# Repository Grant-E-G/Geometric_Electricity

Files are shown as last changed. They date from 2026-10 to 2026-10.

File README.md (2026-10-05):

# Geometric Electricity

A passive LC circuit experiment comparing 85-node Euclidean and hyperbolic disks.

The [project outline](notes/one_and_done_hyperbolic_euclidean_board.md) describes the intended board. The [design and measurement plan](notes/research_plan.md) records calculations, equipment, decisions and remaining validation. Open [the KiCad project](hardware/geometric_electricity.kicad_pro) for the current CAD draft; [reproduction commands](code/README.md) generate simulations and verify connectivity.

The hardware is a design draft. Generated manufacturing files remain previews until routing, procurement and assembly checks pass. Bench validation follows assembly.

## Repository Layout

- `notes/`: research plans, reading notes, project logs, and informal planning.
- `math/`: definitions, theorem targets, proof sketches, examples, and open questions.
- `latex/`: manuscript source, macros, bibliography, and TeX inputs.
- `latex/render/`: rendered PDFs and TeX build products. This directory is ignored by git.
- `code/`: one consolidated simulation, CAD-generation and measurement-analysis script.
- `hardware/`: one KiCad project, sparse adjacency/metric data, BOM.
- `build/`: ignored simulation reports, figures, native checks and manufacturing previews.
- `sources/`: source material used during research.
- `sources/pdfs/`: local PDF references. PDF files are ignored by git.

## Working Sequence

1. Read the design/measurement plan and the original outline.
2. Reproduce simulations, probe loading, tolerance and defect sweeps.
3. Generate the KiCad schematic and placement; route and run native checks.
4. Confirm a landed total **below $200**, including PCB/stencil, shipping, tax,
   consumables and spares. Component precision must not break this constraint.
5. Verify the stencil/assembly map, assemble with a measured reflow profile and
   calibrate the RF fixture and probes.
6. Measure low-order responses and pulses, fit overlapping modes where justified,
   and state partial-spectrum limits explicitly.

All generated reports/previews stay in ignored `build/`. With the user-provided
PCBWay shipping-inclusive quote and $10 stencil, the proposed TDK parts give
$170.34 for lead-free HASL or $194.81 for ENIG. These totals retain $15 component
shipping, $20 tax/import and $20 contingency allowances. Component delivery and
any additional stencil shipping remain unconfirmed. The current Abracon BOM
costs $181.48 with HASL; its ENIG scenario exceeds $200. No purchasing or physical
measurements have occurred.

## Coding Guidelines

- Prefer Rust for implementation work. Use Python as a backup, with type checking.
- Prefer functional code when possible. Relax this guideline when it causes performance issues.
- Long functions are fine.
- Avoid inheritance. Object-oriented design is generally discouraged.
- Avoid excessive code fragmentation. Longer files are acceptable when they keep related logic together.
- Lint code aggressively. Use Black for Python formatting.
- Shorter code is almost always better code.

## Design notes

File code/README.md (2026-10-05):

# Reproducible LC design

`design.py` keeps graph generation, electrical models, KiCad generation and
measurement post-processing together. Python is the backup language allowed by
the repository guidelines: SciPy and KiCad's native `pcbnew` interface make it
appropriate here. No extra simulator framework or application is introduced.

Use KiCad 9, ngspice, system Python 3.10+ with `pcbnew`, and a virtual environment
that can see system packages:

```bash
uv venv --python /usr/bin/python3 --system-site-packages .venv
uv pip install --python .venv/bin/python numpy==2.2.6 scipy==1.15.3 matplotlib==3.10.9 black==26.10.0 mypy==2.4.0 ruff==0.16.10
.venv/bin/python code/design.py build --trials 200
.venv/bin/python code/design.py check
.venv/bin/black --check code/design.py
.venv/bin/ruff check code/design.py
.venv/bin/mypy --ignore-missing-imports code/design.py
```

`build` regenerates the schematic, **placed PCB**,
graphs and BOM. It replaces existing PCB edits/routing; preserve manual changes
before using it. `check` verifies the current board and schematic against the
independently reconstructed graphs without overwriting the copper.
`simulate` reruns the mathematics, tolerances, AC response and two transient
models without regenerating the KiCad files. All intermediate files, plots,
ngspice decks and manufacturing previews are in ignored `build/`.

Run the complete computational measurement suite, including the original
simulations and fresh independent ngspice references:

```bash
.venv/bin/python code/design.py test-simulations --trials 200
```

This preserves the routed PCB and schematic. It adds source-rank/visibility,
inductor SRF and loss, capacitor ESR/ESL and trace/return inductance, signed mutual
coupling, uneven stray capacitance, noisy current reconstruction and scan-probe
deembedding, extended disorder/localization, common-pole/spatial-residue recovery,
held-out frequencies, assembly faults, moving-probe pulses and finite-spectrum
truncation tests. Noise, calibration errors and parasitic values are explicit
sensitivity assumptions; they are not measurements or field-extracted PCB data.
Failed recovery scenarios remain in the report rather than being counted as
numerical failures or hidden. A small fit residual alone does not establish
correct poles or spatial modes.

Generated outputs include:

- `simulation.json` and `simulation.png`: seed, Monte Carlo scenarios, frequency
  clusters, probe/stray sweeps, C choices and illustrative responses.
- `E/H_simulation.npz`: q, voltage eigenvectors, frequencies and loaded AC maps.
- `E/H_pulse.npz`: ideal Gaussian current pulse with series inductor loss.
- `E/H_loaded_pulse.npz`: Gaussian voltage pulse, 50 Ω generator, 1 kΩ injection,
  and two 10 pF probes, simulated independently in ngspice.
- `spice_validation.json`: independent matrix/modal-versus-ngspice errors.
- `test_simulations.json` / `test_simulations.png`: computational measurement
  coverage, parameters, failures and engineering limits for both geometries.
- `E/H_nonideal_ac.npz` and `E/H_nonideal_spice.cir`: nonideal sweeps and separately
  stamped ngspice models, including mutual coupling.
- `E/H_pulse_tests.npz`: complete repeated 85-node scans with a moving probe,
  alongside one acquisition with the scan probe held fixed.
- `E/H_recovery_input.npz` / `E/H_recovery_fit.npz`: the last recovery case;
  all noise levels and seed comparisons are retained in `test_simulations.json`.
- `verification.json`, `erc.json`, `drc.json`: graph/pin and native rule checks.
- `budget.json`: component quantities, spending allocations and unconfirmed quote gates.
- `probe_map.pdf` / `probe_map.csv`: actual signal-pad coordinates, KiCad reference
  and nearest ground contact. Ground contacts include return vias and ground test pads.
- `manufacturing-preview/`: Gerbers including F.Paste, Excellon drills and an
  explicit NOT_FOR_FABRICATION marker; `positions.csv` and `schematic.pdf` / `assembly.pdf` (DNP footprints crossed out).

Record the actual assembly state, L/C/Q calibration, source, scanned node,
probe count, frequency and channel calibration with acquired data. The documented
measurement procedure is in `notes/research_plan.md`.

For one stopped scope acquisition, the optional LAN capture command sets the
waveform readout to RAW ASCII and reads CH1/CH2/CH3 from the same frozen record:

```bash
.venv/bin/python code/design.py capture --host SCOPE_IP --csv build/capture.csv
```

It assumes a SCPI socket at TCP 5555. The command has **not been tested against
the user's scope**; validate this interface and scaling with a known sine first,
or export CSV manually. The front panel must already have 10× probe scaling,
channels enabled and suitable acquisition settings. It does not configure or
control the JDS6600. The first 10,000 RAW samples are read; ensure that interval
contains the desired signal. SCPI failures are reported rather than hidden.

For manual or scripted captures, use exactly these columns (volts already scaled
to the probe tip): `time_s,vin_v,vsource_v,vscan_v`. Analyze a settled sine window:

```bash
.venv/bin/python code/design.py phasor --csv build/capture.csv --frequency 6000000 --sense 1000 --probe-pf 10
```

This fits sine/cosine/DC terms and subtracts source-probe current. If fixture
calibration supports a lumped extra source capacitance, pass `--fixture-pf VALUE`
to subtract it as well (default zero; do not guess it). Distributed fixture
impedance requires a fuller calibration. It assumes a
real sense resistance and calibrated relative channel phase/gain. It leaves the
moving scan probe's network loading in the transfer response; see the explicit
deembedding procedure in the design plan. A synthetic capture checks current
orientation and source-probe subtraction analytically during build/check.

For calibrated, current-normalized complex frequency responses, supply an NPZ
with `frequency_hz[n]` and `impedance_ohm[n,channels]`. Correct moving-probe loading
first; a moving load does not have exact common poles. Seed distinct resonance
clusters from a coarse sweep (one pole pair per degenerate cluster):

```bash
.venv/bin/python code/design.py fit --responses build/responses.npz --initial-mhz 4.42 4.63 --background-order 2 --output build/poles.npz
```

Variable projection fits conjugate pole pairs with complex residues and a local
complex polynomial background on the positive-frequency window. The polynomial
approximates other modes locally; it is not a global passive network model.
Orders 0–4 are supported; compare orders and adjacent-mode counts to detect
model bias. Output includes damping, undamped frequencies,
residues, residual RMS and Jacobian condition. A synthetic two-channel overlap
case checks pole/damping recovery independently; the extended suite also tests
responses of the entire 85-node network with four sources and all scan nodes.
Output NPZ stores complex `background_coefficients[order+1,channels]`,
`background_center_mhz` and `background_scale_mhz`; evaluate the polynomial at
`(frequency_mhz-center)/scale`. Test several seed sets and withhold frequencies
to assess model error. Convergence is not completeness or
identifiability; residues still need calibrated spatial factorization before
becoming the real orthonormal vectors required below.

For **fitted** real orthonormal eigenvectors, provide an NPZ containing `q[m]`
and `vectors[85,m]`. Uniform-L voltage vectors can be used directly; for disordered
L, convert to coordinates of the self-adjoint operator described in the plan.
Raw voltage maps at unresolved peaks are not eigenvectors.

```bash
.venv/bin/python code/design.py derive --eigenpairs build/E_simulation.npz --output build/E_analysis.npz
```

This produces the finite-graph heat kernel/trace, zeta at s=1,2,3, Q inverse and
participation ratios. Fewer than 85 modes are explicitly marked partial. Only
when recovery of **all lowest m modes** has been established may
`--lowest-modes-complete` be used to add rigorous heat-trace/zeta tail bounds.
This command is not a common-pole fitting implementation.

For uniform-time pulse scans, provide `time_s[time]`, `voltage_v[time,85]` and
`source` in an NPZ:

```bash
.venv/bin/python code/design.py propagate --waveforms build/H_loaded_pulse.npz --geometry H --output build/H_propagation.npz
```

This extracts Hilbert envelopes, masked instantaneous phases and distances in the
true metric and embedding. Compare only reproducibly triggered scans before
reflections dominate. Hilbert phase alone does not establish causal arrival time.

The reproducible assertions and native checks are meaningful electrical/topology
checks, not substitutes for physical calibration, noise characterization or
fabrication readiness. Read the current design status before using any Gerbers.

Export/import routing through a Specctra-compatible router without regenerating
the schematic or placement:

```bash
.venv/bin/python code/design.py route-export
# Route build/routing.dsn in a compatible router, saving build/routing.ses.
# Preserve the ground returns; in Freerouting use -inc GND and -mt 0.
.venv/bin/python code/design.py route-import --session build/routing.ses
.venv/bin/python code/design.py check
```

The exported design assigns ground to its own class and protects its existing
return copper and excludes pours from the router's copy. The initial signal pass
may skip that class; a final repair pass must also connect remaining ground items.
Native refill/connectivity checks remain mandatory.
The saved board was routed with Freerouting 1.9.0, then repaired locally in KiCad
copper geometry. The initial router command was `java -jar freerouting-1.9.0.jar
-da -de build/routing.dsn -do build/routing.ses -mp 20 -mt 0 -inc GND`; the ground
repair pass omitted `-inc GND`. This version required a local graphical display.
Preserve the saved routed PCB: `build` produces placement, and a new router
run can produce different copper. `check` is the authority for the current native
connectivity result. Refresh exports after copper edits using
`python -c 'import sys; sys.path.insert(0, "code"); import design; design.export_preview()'`
with the same virtual environment, then run `check` again. Export refresh also
updates the ground-contact map and opens selected standard ground vias on the
front solder mask.
Import refills the ground plane. A successful router import is not a passing
DRC or permission to fabricate. Current manufacturing output is explicitly a
preview. The budget uses user-provided PCBWay fabrication/shipping and stencil
quotes; component shipping, consumables, tax/import and contingency remain allowances.

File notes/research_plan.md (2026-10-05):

# Geometric Electricity: design and measurement plan

Design baseline: 2026-10-05. The original idea remains in
[the project outline](one_and_done_hyperbolic_euclidean_board.md).

## Question and scope

Can one passive PCB distinguish the low-order spatial spectra and propagation
of Euclidean and hyperbolic disks using the equipment already available, and
support reproducible finite-graph spectral analysis?

Keep one board, one assembly, two independent 85-node networks, common ground,
and no active switch matrix. The intended comparison is between induced regular
triangular disks with coordination six and seven. Electrical traces do not set
the simulated metric; connectivity does. Physical placement coordinates and
mathematical embedding coordinates must remain separate.

## Equipment and measurement contract

The user confirmed a Rigol DHO924S (four channels, 250 MHz), JDS6600-60M generator,
PVP3150 probes, DE-5000 with TL-21/TL-22 fixtures, and T-962 oven. There is no VNA.
Use 10× probes, modeled as 10 MΩ in parallel with 10 pF at **each** connected
network node. Also simulate 15 pF uncertainty and 50 pF loading. CH1 measures
actual voltage before the injection resistor; CH2 remains at the source node;
CH3 scans the response. CH1 capacitance is on the generator side of the resistor,
not another network-node load. Ground every probe to the common ground.

The JDS6600's sine-frequency limit does not establish pulse rise time or arbitrary
waveform bandwidth. Confirm its delivered pulse on CH1 and use the measured
waveform for propagation interpretation. The DE-5000 is useful for loose-part
screening, but its 100 kHz ceiling cannot certify MHz Q. Do not treat measured
100 kHz Q or DC resistance as the loss at a circuit resonance.

## Operator and exact boundary convention

Let A be the adjacency matrix and d the retained degree. For each missing neighbor,
install one extra coupling capacitor to ground. Then

\[
Q=\operatorname{diag}(d)-A+\operatorname{diag}(q-d)=qI-A.
\]

This is a positive Dirichlet operator, not the zero-mode-bearing free-boundary
Laplacian. The default hardware has 330 pF per retained edge and **330 pF per
missing neighbor**, including multiple capacitors in parallel where necessary.
No special 990 pF or 1320 pF purchase is required. Removing all capacitive
boundary terminations would produce the free graph Laplacian; removing only a
few makes a local boundary defect and must not be called a global Neumann change.

For uniform L and C,

\[
J(\omega)=i\omega C Q+\frac{1}{i\omega L}I,
\qquad f_k=\frac{1}{2\pi\sqrt{LCq_k}}.
\]

Ascending q means **descending electrical frequency**. Low-order drum modes
are the highest resonances. With losses, the simulator stamps the full series
R-L branch rather than adding an arbitrary damping term to a graph Laplacian.
The Q sweeps use constant R = 2π(8 MHz)L/Q; consequently Q varies with frequency.
These are engineering sensitivity scenarios, not manufacturer broadband models.

With inductance disorder, the measured voltage eigenvectors are generalized
modes of C_matrix v = (1/ω²) diag(1/L_i) v. Ordinary orthonormal eigenvectors are
obtained after dividing voltage coordinates by sqrt(L_i). The self-adjoint
operator is S = diag(sqrt(L_i)) C_matrix diag(sqrt(L_i))/(L_nom C_nom).
Do not apply uniform-L orthogonality or heat-kernel formulas blindly to raw
voltage maps from a disordered circuit.

## Graph construction and mathematical validation

The Euclidean disk consists of axial triangular-lattice coordinates satisfying
 a²+ab+b² ≤ 21. It has 85 nodes, 222 retained edges and 66 missing-neighbor
capacitors. Graph-distance shells contain 1, 6, 12, 18, 24, 24 nodes.

The hyperbolic disk is the radius-three graph ball of the regular {3,7}
tessellation. Construct neighbors with Poincaré disk isometries and sevenfold
rotations. Its edge distance satisfies cosh(ell)=cos(2π/7)/(1-cos(2π/7)); the
embedding uses curvature -1. It has shells 1, 7, 21, 56, 196 retained edges and
203 missing-neighbor capacitors. Distances for the curvature -4 convention in
the reference are half these distances. This graph is generated independently;
we have not claimed equality to the reference's original node numbering or its
archived Euclidean adjacency file.

Checks cover node count, connectivity, degree, cyclic symmetry, positivity,
row sums, eigen-equation residuals, independently exported schematic pin nets,
and PCB capacitor incidence plus boundary multiplicities. Pin/net parity alone
does not prove that copper is routed: KiCad DRC must separately pass.

## Electrical scale and simulation findings

At 1 µH / 330 pF the nominal full spectrum is:

| Geometry | Minimum electrical frequency | Maximum electrical frequency |
| --- | ---: | ---: |
| Euclidean | 2.9455 MHz | 15.6483 MHz |
| Hyperbolic | 2.8070 MHz | 7.6601 MHz |

Thus the outline's estimated 1.4–9.6 MHz window is not the spectrum of these
specific disks. Both computed windows are accessible to the confirmed generator
and scope. Start with a 2–17 MHz sweep and refine to ≤5 kHz spacing near selected
peaks. The continuum interpretation is restricted to low-order modes.

The first six distinct nominal resonance clusters, in increasing q order, are:

| Geometry | Electrical frequencies, MHz |
| --- | --- |
| Euclidean | 15.6483, 9.9262, 7.5118, 7.0204, 6.1951, 6.1108 |
| Hyperbolic | 7.6601, 6.1478, 5.4316, 4.9893, 4.6011, 4.4550 |

These frequency lists by themselves do not label radial/angular modes. Determine
spatial profiles and angular content before identifying a reordered radial mode.

Seed 20261005, 200 trials per combination, independent uniform L tolerance,
independent edge C tolerance (including the budget ±5% case), conservative
lumped boundary-bank tolerance,
and 2 pF uniform stray capacitance:

| L tolerance | C tolerance | Scenario Q at 8 MHz | 5th percentile worst first-six-cluster subspace overlap, E / H |
| --- | --- | ---: | ---: |
| ±10% | ±5% | 36 (budget baseline) | 0.827 / 0.852 |
| ±10% | ±2% | 45 | 0.850 / 0.870 |
| ±5% | ±2% | 50 | 0.962 / 0.968 |
| ±2% | ±2% | 50 | 0.994 / 0.991 |

All scenarios use the same random draws within each geometry for a fair
comparison. Q affects the linewidth screen, not the lossless eigenspace overlap.
For the budget case, the 95th percentile maximum first-12 frequency shift is
about 1.6% for E and 1.7% for H. This is a simulation of bounded independent
uniform variation, not a manufacturing yield guarantee. Correlated lot errors
can move the common frequency scale and must be checked experimentally.

Degenerate eigenspaces are compared by principal angles after eigenvector-based
assignment; an arbitrary rotated basis inside a degenerate space is not counted
as a failure. Disorder and spectral resolution are separate issues. The cheap
10% option does not destroy all low-order identification, but gives worse spatial
fidelity. Higher-order modes are not covered by these low-order overlap numbers.
The gap-versus-linewidth screen is deliberately conservative: Q≈50 does not
separate all first-six clusters; the hyperbolic 4.601/4.455 MHz pair is especially
close. Q≈100 improves this screen substantially. It does not follow that 85
individual peak maps will be recoverable with either part.

With 2 pF stray at every node and two 10 pF probes at the designated intermediate
source and boundary node, the largest first-12 frequency shifts are about 1.08%
for E and 0.26% for H. Uniform stray is a simplification; copper extraction,
uneven node capacitance, inductor SRF, mutual inductance, capacitor ESR/ESL,
connector/cable capacitance and channel calibration still need assessment.
The simulations sweep C = 220, 330, 470, 680 and 1000 pF. Retain 330 pF as the
baseline because it preserves useful MHz bandwidth with modest modeled probe
loading. Changing C alone does not improve normalized mode spacing or Q.

Independent ngspice AC checks agree with the matrix solution to <10⁻⁶ relative
error. The ideal current-pulse transient agrees within 0.1% of peak voltage.
A second ngspice transient includes a 50 Ω generator, 1 kΩ injection resistance
and source/scan probe capacitance. Synthetic waveforms are predictions, not
measurements of the JDS6600's pulse or a fabricated board.

## Extended testing simulations

Run `.venv/bin/python code/design.py test-simulations --trials 200`. This
regenerates the original simulations and independent ngspice references before
running the additional tests; it preserves the routed CAD. Results and plots
are in `build/test_simulations.json` and `build/test_simulations.png`. Generated
artifacts stay ignored; the implementation stays in the existing design script.

The suite covers source visibility, moving-probe deembedding, assumed measurement
noise and calibration errors, component/lot tolerance and localization, coil
self-capacitance, capacitor ESR/ESL, trace/ground inductance, mutual inductance,
assembly faults, loaded pulses, full-network overlapping-pole recovery, and
partial heat/zeta/Green reconstruction. The nonideal circuit is independently
cross-checked against ngspice; matrix heat/Green calculations are checked against
independent matrix exponential/inverse calculations. Checks include passivity
and source/probe loading, with 10 pF per actively probed node.

Important numerical findings from the seeded 200-trial run:

- Four selected sources span the first six ideal mode clusters for both graphs.
  A center source alone misses symmetry modes. Rank does not establish practical
  signal-to-noise or identifiability of the complete spectrum.
- The fifth-percentile minimum overlap of the first six mode subspaces is about
  0.82/0.83 (E/H) for ±10% L, ±5% C; ±5% L improves this to 0.95/0.96.
  ±20% L with ±5% C drops it to 0.60/0.45. These are normalized self-adjoint
  subspaces, with independently sampled boundary capacitors; they differ from
  the earlier conservative, correlated-bank tolerance calculation above.
- Exact simulated moving-probe deembedding recovers the intrinsic maps to
  numerical precision. Assumed 0.5% gain error, 0.5 degree phase error and
  2 pF probe-capacitance uncertainty give roughly 2–3% map error through much
  of the resonant band. Noise trials assume independent white sample noise,
  20 cycles at 1 GS/s and 200 mVpp generator output. These assumptions are
  sensitivity cases, not measured Rigol noise specifications.
- Loaded-pulse state-space and ngspice results agree within 0.1% of peak.
  Repeating a scan with the probe moved changes the reconstructed wave map by
  about 1.3% relative to a fixed-probe reference. Threshold arrivals and
  voltage-weighted metric radii are diagnostics, not causal propagation speeds
  or proof of unreflected geodesic transport.
- Full-network fits use multiple sources, held-out frequencies and two seeds.
  Q=36 supports useful selected overlapping-mode recovery at low added noise;
  Q=20 produces substantially worse spatial recovery even with very small fit
  residuals. Convergence and a small residual alone do not qualify eigenpairs.
- With only 12 modes, the dimensionless t=1 heat trace captures about 90% for
  both graphs, but zeta(s=1) captures only 47%/31% (E/H). The corresponding
  Green inverse has about 34%/65% relative Frobenius error. Report partial
  quantities and tested tail bounds rather than claiming complete spectra.

Parasitic values and mutual couplings are illustrative stress cases, not PCB
field extraction or manufacturer broadband models. Specified Q at 10 MHz and
SRF do not determine the actual inductance/loss curve. Real fixture, RF component
qualification and channel calibration remain necessary with the owned equipment.

## Parts decision and assembly

The budget is a hard **under $200 USD all-in** limit for one populated board,
including spare parts, bare PCB order, stencil, paste/consumables, shipping, tax
and import charges. Existing measurement equipment and the owned oven are not
new purchases. Do not spend the allowance on precision components before obtaining
landed fabrication prices.

The cost-controlled CAD baseline is **Abracon AIML-0805-1R0K-T**, 1 µH,
±10%, Q≥45 at 10 MHz, 0805, and **Yageo CC0603JRNPO9BN331**, 330 pF,
±5%, C0G/NP0, 50 V, 0603. The current Abracon revision F specifies minimum
SRF 95 MHz for this value. A Q specification at 10 MHz does not establish Q
throughout the measurement band: the simulations also include Q=36 at 8 MHz,
corresponding to the same constant series resistance as Q=45 at 10 MHz.
Use standard KiCad 0805/0603 footprints, front-side assembly and one stencil.
Headers are installed afterward by hand. No custom inductor footprint is needed.

The following combines the user-provided PCBWay quote with remaining allowances. Supplier
component listings were checked 2026-10-05; stock/prices can change. The board is
150×130 mm, outside common 100×100 promotional pricing. The user quotes $72.76 for lead-free HASL or $97.23 for ENIG, including
PCB shipping, plus $10 for a stencil. Populate
one board; budget any mandatory minimum bare-board order in the fabrication row.

| Item | Buy quantity / allowance | USD |
|---|---:|---:|
| Abracon inductors, cut tape (170 used + 30 spare) | 200 × $0.09380 | 18.76 |
| Yageo capacitors (687 used; spare/defect stock included) | 800 × $0.0062 | 4.96 |
| 1 kΩ 1% 0603 resistors and two 1×02 headers, with spares | allowance | 5.00 |
| PCBWay bare PCBs, lead-free HASL, including shipping | user quote | 72.76 |
| Front stencil | user quote | 10.00 |
| Component-order shipping | provisional allowance | 15.00 |
| Paste, hookup wire, probe ground adapters, consumables | allowance | 15.00 |
| Tax/import charges | allowance | 20.00 |
| Contingency | reserve | 20.00 |
| **Planned ceiling** | **$18.52 below the hard limit** | **181.48** |

Component sources: [DigiKey US cut-tape listing](https://www.digikey.com/en/products/detail/abracon-llc/AIML-0805-1R0K-T/2662996),
[LCSC capacitor listing](https://www.lcsc.com/product-detail/Multilayer-Ceramic-Capacitors-MLCC-SMD-SMT_YAGEO-CC0603JRNPO9BN331_C62784.html),
and [Yageo part specification](https://yageogroup.com/download/specsheet/CC0603JRNPO9BN331).
Buy cut tape rather than a full reel or paid Digi-Reel. Do not count a promotional
PCB price as the landed cost. If actual invoices exceed an allocation, use the
contingency only while keeping the total strictly below $200. If the total still
exceeds the ceiling, the design fails its cost acceptance gate; revise suppliers,
stencil choice or board size before ordering. No order has been placed.

### Cheaper purchasing candidates

The preferred alternate is **TDK MLF2012A1R0JT000**, LCSC **C165812**:
1 µH ±5%, Q minimum 45 at 10 MHz and SRF minimum 120 MHz. The checked
200-piece tier is $0.0381 each, **$7.62 total**, versus $18.76 for Abracon.
Together with repricing the unchanged Yageo capacitors to $4.96, this saves
**$16.58 versus the original $194.16 allocation**. Using the PCBWay quotes and retaining $15 for component shipping gives
**$170.34 with HASL** or **$194.81 with ENIG**, leaving $29.66 or $5.19
below $200. Both include the stencil, $15 consumables, $20 tax/import and $20
contingency. Component shipping is an allowance; extra stencil shipping and
quote tax treatment remain unconfirmed. The current Abracon BOM is $181.48
with HASL or $205.95 with ENIG. Finish remains a purchasing choice.
The suite includes the exact ±5% L/±5% C and 120 MHz SRF cases.

Sources: [TDK specifications](https://product.tdk.com/en/search/inductor/inductor/smd/info?part_no=MLF2012A1R0JT000),
[LCSC TDK stock/price](https://www.lcsc.com/fr/product-detail/C165812.html), and
[LCSC Yageo price](https://www.lcsc.com/product-detail/C62784.html).
Prices were checked 2026-10-05; confirm stock and the combined landed quote.

| Candidate | Actual buy-quantity cost | Assessment |
|---|---:|---|
| TDK MLF2012A1R0JT000, 200 | $7.62 | Preferred; tighter tolerance and adequate specified Q/SRF |
| FH CMI201209U1R0KT, 200 | $5.06 | Saves only $2.56 more; Q minimum 35 at 10 MHz and SRF 75 MHz; lower-Q stress case included |
| FH CMP201209UD1R0MT, 200 | $6.62 | Only $1 cheaper than TDK, ±20% and unqualified RF Q; reject |
| TDK MLF2012A1R0JTD25 / TAI-TECH FCI2012F-1R0K | — | Checked listings out of stock; exclude from a purchasable budget |
| Walsin HH18N331J500CT | — | Cheaper C0G listing out of stock; exclude |
| CCTC TCC0603COG331J500CT, 800 | $5.60 | Costs more than the unchanged Yageo part |

Other checked listings: [FH RF inductor](https://www.lcsc.com/product-detail/C99367.html),
[FH 20% part](https://www.lcsc.com/product-detail/C401475.html),
[out-of-stock TDK variant](https://www.lcsc.com/product-detail/C404436.html),
[Walsin capacitor](https://www.lcsc.com/pl/product-detail/C3842704.html), and
[CCTC capacitor](https://www.lcsc.com/de/product-detail/C376783.html).

The CAD and BOM still name Abracon: this identifies an alternate rather than
silently approving a purchasing or fabrication release. TDK's 0805 body fits
its envelope, but its recommended land pattern has a 1.0 mm inner pad gap
versus 1.25 mm in the existing standard KiCad footprint (both 1.2 mm pad width).
Review the terminal overlap and reflow a sample before releasing the alternate;
use the manufacturer's recommended pattern if qualification requires a change.
Its 0.30 Ω maximum DCR must not be substituted for MHz series resistance.
Do not trade C0G for a voltage-dependent dielectric or choose generic power
inductors with unspecified RF Q just to save another dollar.

Bourns CM453232-1R0JL (5%, Q≥50 at 7.96 MHz, 1812) remains a simulation
comparison, not an alternate that fits the present footprint. Its current
recommended land pattern differs from the standard 1812 footprint, so any future
upgrade requires a new verified footprint and layout. The expensive 1% capacitor
option is rejected. DE-5000 measurements can record component variation, but do
not assume its 100 kHz inductance measurement establishes RF Q or exact RF L.
Use a noninductive 1% injection resistor and calibrate its effective complex
impedance if phase precision warrants it.

T-962 drawer clearance must be checked against the actual usable tray, not only
nominal oven specifications. Keep 130 mm along the 180 mm drawer direction.
Use a thermocouple on the populated board and a profile compatible with the
actual solder paste and the inductor's specified reflow limits. Oven presets do
not establish the component temperature profile.

## Placement, routing and sparse controls

The KiCad project uses a 150 × 130 mm outline and two copper layers. Start with
recognizable elliptical graph shells, then relax actual component courtyards.
A successful placement is not evidence of a completed RF layout; record all DRC
results, copper continuity, label readability and return paths before release.
Node signal pads and nearby ground access support manual probing. Some labels
are displaced up to 12 mm to avoid pads and other silkscreen. Use the generated
`build/probe_map.pdf` and `build/probe_map.csv` to identify the **actual signal
pad**, and find its explicit testpoint reference in KiCad. Never assume the pad
closest to displaced text is the corresponding node. `graphs.json` records actual
placed signal coordinates separately from the mathematical metric and includes
nearby ground coordinates; some ground contacts are exposed return vias. A removable
patch selects one source; unused nodes are not connected to a switch matrix.
Source choices are center, shell two, boundary and a rotated shell-two partner.
Permanent long traces to a bank of duplicate node pads are avoided. The removable
source patch still has capacitance and inductance: use the shortest practical
connection, keep its geometry fixed, and calibrate it with the injection fixture.
At these frequencies, current inferred across the 1 kΩ resistor includes current
into the patch as well as the source probe. Subtract a measured fixture admittance
when extracting network impedance; do not attribute that current to the LC disk.
Record any extra source-node load in the model.

Six chosen retained edges on each geometry have a nominal capacitor plus an
unpopulated parallel footprint. Replace the nominal capacitor with ~165 pF for
weaker coupling, populate the parallel 330 pF for stronger coupling, or remove
the nominal capacitor for an open edge. Changes leave traces intact. Rank
candidate edges by low-mode voltage-difference sensitivity and distribute them
across graph shells; record the exact selected edges in graphs.json and BOM.
`simulation.json` contains predictions for opening, halving and doubling each
selected edge, plus removing one boundary capacitor. It reports frequency shifts
and low-mode inverse participation ratios; changed sorted indices are not assumed
to preserve mode identity. The assembly PDF marks the parallel DNP footprints.
For local boundary experiments, remove/repopulate selected individual boundary
capacitors. Changing one of several parallel capacitors gives a known step in
termination strength. It does not change the global boundary condition.

Short ground-return vias and ground pours on both sides connect the reference
around routed signal paths. Pours use full pad connections, 0.25 mm clearance
and 0.15 mm minimum copper width; the many return vias stitch the two sides.
Full ground connections increase heat sinking at assembly, reinforcing the need
for a measured reflow profile. The routing exchange excludes pours, preserves
existing return copper and refills the native KiCad pours after import. The initial
signal pass may skip the ground class; the final connectivity check includes it.
The 0–10 pF stray sweep is a first capacitance budget; it does not validate
RF ground impedance or layout capacitance extraction. Inspect actual routed
lengths and ground-plane continuity before treating this as the final placement.

The saved board is routed. Native KiCad 9.0.9 checks on 2026-10-05 reported
zero DRC violations, zero unconnected items and zero ERC violations; independently
reconstructed graph edges, boundary banks and schematic/PCB pins agree. Routing
used Freerouting 1.9.0 followed by local copper repairs and native pour refill.
A back-layer detour permits the last ground stitch, using a 0.50 mm via with
0.30 mm drill; other return vias use 0.60/0.30 mm. Selected 0.60 mm ground vias
in the probe map have explicit front solder-mask openings; the small stitch is
kept tented. The saved board preserves these routing edits. Regenerating
placement does not reproduce them automatically.
The routed layout contains 31 signal vias and 590 ground vias, with 53 selected
ground vias exposed on the front. The longest individual signal segment is
7.10 mm; this is not an extracted pad-to-pad path length or inductance bound.
Mapped ground-contact distances are at most 6.86 mm for E and 8.17 mm for H.
Check the actual probe spring or short ground adapter against these coordinates;
long clip leads require separate fixture characterization.

## Measurement sequence with existing equipment

1. Calibrate probe compensation, 10× scope scaling, common grounding, relative
   channel gain and phase using the same sinusoid over 2–17 MHz. Record calibration
   data and connected-probe count. Select acquisition bandwidth/sample rate to
   capture ≥10 points per cycle; use ≥20 cycles and averaging when needed.
2. Check the injection interface against known R/C loads. Use CH1 at the actual
   resistor input and CH2 at its output. Start at 200 mVpp generator amplitude,
   zero DC offset, and check linearity by repeating at half amplitude.
3. Measure representative loose L parts in a repeatable parallel-LC fixture at
   the relevant MHz frequencies using the generator and scope. Account for fixture
   and probe C and source-resistor loss. This qualifies RF Q without buying a VNA.
   Loose capacitors can be screened by the compensated DE-5000. Measuring network
   components in circuit will include parallel paths and is not a part-value test.
4. Sweep each designated source and repeat for both geometries. Compute complex
   source impedance rather than relying on visible voltage peaks alone. The
   generator's front-panel voltage is not the calibrated input current.
5. At each selected resonance, scan all 85 node pads with CH3 while CH2 remains
   at the source. Revisit reference nodes periodically to detect drift. Include
   narrow frequency windows around overlapping modes, not just one frequency.
   Scan multiple sources so an eigenvector zero at one source is not missed.
6. Fit common poles and residues across complex response maps. For separated
   poles, a residue vector estimates a spatial eigenvector up to normalization.
   Overlapping/degenerate poles require multiple frequencies/sources and subspace
   fitting. Full 85-mode reconstruction is an additional identifiability/noise
   problem, not a promised consequence of 85 accessible pads. The `fit` command
   estimates common conjugate pole pairs and residues by variable projection.
   It has recovered synthetic overlapping modes from the full 85-node networks,
   with held-out frequencies and multiple initial seeds. Its complex local
   polynomial background approximates nearby modes over the fitted window; it
   is not a global passive circuit model. It remains unvalidated against this
   equipment or a fabricated board. Moving-probe deembedding and
   channel calibration are prerequisites. Inspect fit residuals, conditioning,
   multiple seed sets and held-out frequencies before using fitted eigenpairs.
7. Repeat identical pulse injections at a boundary node and capture every node
   with the same trigger/reference. Characterize the delivered pulse first,
   choose a repeat period longer than the observed decay, and compare envelopes
   and instantaneous phases before boundary reflections dominate. Use metric
   coordinates, not PCB millimeters, to compare geodesics.
8. Change one defect or one local boundary bank at a time, record the assembly
   state and repeat the relevant measurements. Analyze localization through
   participation ratio and eigenvector/subspace changes, accounting for probe load.

Let Vin, Vs and Vi denote simultaneously measured complex voltages. With a real
sense resistor R, the current delivered past it is (Vin−Vs)/R. Remove source-probe
current Ys Vs, where Ys=1/10 MΩ+iωCprobe. Then Zss=Vs/Igraph and Zis=Vi/Igraph.
This is the calculation implemented by the CSV phasor command. It removes the
source probe's shunt current; it does **not** remove the moving scan probe from
the rest of the network.

To deembed the moving scan probe exactly in the lumped linear model, first
measure each Zii without CH3, correcting the CH2 source probe as above. With CH3
at i, the measured transfer is Zis_loaded = Zis/(1+Yi Zii). Thus
Zis = Zis_loaded (1+Yi Zii). Do not leave two probes on the same diagonal node
without counting both. Close to resonance this correction can amplify noise;
propagate calibration uncertainty and compare probe-loaded simulations.

## Derived mathematics and acceptance criteria

For a complete orthonormal eigenbasis of the specified self-adjoint graph operator,
compute K(t)=U diag(exp(-tq)) Uᵀ, heat trace, ζ(s)=Σq⁻ˢ, Q⁻¹ and participation
ratios. These are finite-disk observables, not an infinite-plane spectral zeta or
continuum heat kernel. Positive q avoids an arbitrary zero-mode cutoff.

If only m low modes are measured, report partial sums/kernels. When all lowest m
modes (including partners) are known to have been recovered, the unmeasured heat
trace tail is bounded by (85−m) exp(-t q_m); for s>0, the zeta tail is bounded by
(85−m) q_m⁻ˢ. For incomplete mode selection these bounds are unavailable. The
analysis command requires an explicit flag before producing these bounds.
A resolvent measurement is a frequency-dependent inverse admittance and includes
loss/source/probe effects; Q⁻¹ from eigenpairs is a separate mathematical object.

Fabrication gates are: complete routing and native DRC/ERC; independent graph/pin
parity; readable node/source/defect maps and usable ground access; actual part
MPNs and stencil verification; and a landed purchasing total strictly below
$200 including contingency. Keep manufacturing output marked as previews until
these gates are met. Screen representative loose inductors in the RF fixture
before committing to a full order where practical.

Routing and electrical connectivity gates pass for the current saved board.
Landed supplier quotes, physical ground-spring/patch fit, stencil inspection and
the measured assembly profile remain outstanding. The native checks do not
establish RF parasitics or experimental recovery of the complete spectrum.

After assembly, acceptance requires a measured/calibrated RF loss model,
adequate loaded signal/noise and repeatability, and demonstrated low-mode
separation or validated multi-pole extraction. These are physical experiment
steps, not results already obtained by simulation. Full-spectrum trace/zeta
claims additionally require complete eigenpair recovery or a stated truncation
bound. A fabricated prototype does not by itself validate the scientific claims.

## Primary references

- [Lenggenhager et al., paper and supplementary methods](https://arxiv.org/pdf/2109.01148).
- [Published article and archived data/code link](https://www.nature.com/articles/s41467-022-32042-4).
- [Abracon AIML-0805 specifications, revision F](https://abracon.com/Magnetics/chips/AIML-0805.pdf).
- [Bourns CM453232 datasheet](https://www.bourns.com/pdfs/cm.pdf) and
  [2025 change notice](https://www.bourns.com/docs/technical-documents/product-change-notifications/Bourns_IC25125_Chip_Inductors_PCN.pdf).
- [TDK NLV32 specifications](https://product.tdk.com/en/search/inductor/inductor/smd/info?part_no=NLV32T-1R0J-EF).
- [Obsolete TDK NL453232 status](https://product.tdk.com/en/search/inductor/inductor/smd/info?part_no=NL453232T-1R0J-PF).
- [DE-5000 manual](https://www.ietlabs.com/pdf/Manuals/DE_5000_im.pdf).
- [Rigol programming guide](https://download.rigol.com/en/Manual/Digital%20Oscilloscope/DHO900/DHO800900_ProgrammingGuide_EN.pdf).
- [JDS6600 supplier specifications](https://www.joy-it.net/en/products/JT-JDS6600).

## Blind-spot audit: scope, cost and geometric distinctness

Audit date: 2026-10-05. This is a scope analysis, not a CAD revision or a
purchasing release. Additional ideal-graph calculations use the exported graph
construction, direct symmetric eigendecomposition and the action of a one-step
sixfold/sevenfold rotation on each eigenspace.

The original outline chose 85 nodes per graph and many outputs; those are scope
choices, not requirements established by a minimum-size or statistical-power
study. At the proposed TDK/Yageo tiers, the 170 inductors and 687 capacitors
actually populated cost $10.73. The buying allowance is $12.58 for those parts,
plus $5 for interfaces/spares. The earlier $160 fabrication/shipping/other
allocation is superseded by the PCBWay quote scenarios above. Quotes and
remaining allowances are not actual invoices. Saving pennies per passive cannot address most of the budget.
Full node access costs board space, routing effort and manual acquisition time,
although copper test pads do not require separate purchased components.

| Assumption to relax | Consequence and limit |
|---|---|
| Every listed mathematical output must succeed in V1 | Make a normalized low-mode spectrum and a few spatial maps the acceptance target. Heat/zeta are derived from the same data, not independent confirmations; retain incomplete-spectrum labels. |
| Both graphs must have 85 nodes | Test smaller candidates before layout. A 37-node Euclidean disk uses 90 edges + 42 boundary capacitors; a 29-node hyperbolic radius-two disk uses 63 + 77. Together: 66 L and 272 C, versus 170 L and 687 C. Ideal ordering remains distinct, but boundary/continuum fidelity and loaded noisy recovery are not qualified. |
| Equal node counts constitute matched geometry | Equal N does not match radius or boundary fraction. A 37-node E / 85-node H comparison matches three graph-distance shells; it is another legitimate experiment, not an equivalent control. |
| One 150×130 mm outline is necessary | Investigate tighter placement or panel arrangements and obtain real landed quotes. A 100×100 outline has 49% less area, but fit, ground access and routing are unproven; promotional savings cannot be assumed. |
| One capacitor per missing neighbor is necessary | Only the total shunt capacitance matters ideally. Replace 269 boundary capacitors with 86 equivalent-value banks if C0G sourcing, tolerance and RF parasitics qualify. This removes 183 placements; cheap baseline capacitors make dollar savings small. |
| Every frequency/source needs a complete spatial map | Use center/off-center discovery sweeps and selected shell/node maps first. Four-source full coverage is useful for degeneracies, but two-node discovery is not full mode recovery. |
| Absolute frequencies are the main geometry test | Use eigenvalue ratios and spatial symmetry to remove a common LC scale error. Individual disorder, boundary changes and RF loading still require calibration. |

Do not relax C0G behavior, qualified RF loss, correct boundary operator,
source-current calibration, or multiple-source access merely to save small sums.
The current ±5% inductor alternate already improves tolerance while reducing
cost. A no-VNA workflow is viable but transfers effort into fixture qualification,
channel calibration and probe deembedding. Four sources × 85 nodes × two graphs
means 680 source/node combinations for a complete response map, before diagonal
calibration, drift checks or repeats; frequency sweeps may be automated while
probe movement remains manual. Physical acquisition time is a hidden constraint.

The two current networks are topologically disks, both triangulated and simply
connected. The difference is geometric/connectivity curvature, not different
genus or a topological phase. In the bulk, six equal triangles meet at an E node
and seven at an H node. The q=6/7 choice also changes local electrical loading;
raw peak separation alone cannot attribute an effect uniquely to curvature.

| Ideal-graph measure | E85 | H85 |
|---|---:|---:|
| Boundary nodes | 30/85 (35.3%) | 56/85 (65.9%) |
| Graph-distance shells | 1,6,12,18,24,24 | 1,7,21,56 |
| Mean retained degree | 5.224 | 4.612 |
| First angular-sector eigenvalue / ground eigenvalue | 2.485 | 1.552 |
| First threefold-sector eigenvalue / ground eigenvalue | 6.380 | 2.357 |
| Second rotation-invariant eigenvalue / ground eigenvalue | 4.968 | 2.957 |

Thus the second rotation-invariant mode lies below the first threefold-sector
mode in E, but above it in H. Electrical frequency runs in the reverse order.
These are exact finite-graph rotational sectors; angular labels are defined
modulo six/seven and do not independently prove continuum radial labels. This
scale-independent ordering is a stronger primary target than the roughly
15.65 versus 7.66 MHz highest resonance. The 37-node E and 29-node H candidates
retain the corresponding ideal ordering (4.648 < 5.649 in E; 3.135 > 2.827 in H).
They are interesting small demonstrations, not validated replacement designs.

Boundary leverage is substantial: uniformly multiplying termination C by 0.9
or 1.1 changes the ideal lowest eigenvalue by -3.6%/+3.1% in E and -4.2%/+3.6%
in H. The first angular/ground ratio changes only about 0.2% in E but about
1.2% in H. This symmetric stress case is not random tolerance or a complete
boundary robustness study. A larger H disk still has a substantial boundary;
do not assume that adding nodes automatically yields a bulk-only experiment.

The Euclidean graph is an essential benchmark for the apparatus and analysis;
its isolated scientific novelty is modest. H adds stronger growth, boundary
leverage and changed angular/radial ordering, but needs more careful finite-size
interpretation. The pair is most valuable as a controlled measurement exercise.
The basic hyperbolic-drum mode reordering and geodesic propagation have already
been experimentally demonstrated in [Lenggenhager et al., 2022](https://www.nature.com/articles/s41467-022-32042-4).
A credible improvement here would be a transparent inexpensive measurement,
uncertainty/boundary study, or stronger quantified reconstruction—not merely
repeating known geometry with additional postprocessed functions.

Before committing a smaller design, compare a prespecified normalized ordering
and symmetry observable against noise/disorder, boundary changes and size changes.
For propagation, compare hyperbolic versus Euclidean/graph-distance explanatory
models on held-out nodes/time windows rather than fitting only the metric assumed
by construction. Existing simulations mostly validate implementation and
sensitivity; they do not yet constitute this competing-hypothesis test.

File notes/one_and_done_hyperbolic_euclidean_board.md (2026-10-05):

# One-and-Done Hyperbolic / Euclidean LC Board
## Revised architecture for a single fabrication + assembly

## Goal

Collapse the staged program into **one PCB, one stencil, one reflow assembly**, while preserving as much mathematical range as possible.

The board should provide:

1. a full 85-node Euclidean \(\{3,6\}\) network;
2. a full 85-node hyperbolic \(\{3,7\}\) network;
3. identical electrical scaling on both halves;
4. node-by-node probing;
5. a small number of built-in boundary/defect controls;
6. enough measurement access that the same hardware supports:
   - eigenvalue/eigenvector comparison;
   - heat kernel / heat trace;
   - spectral zeta function;
   - Green's functions / resolvent measurements;
   - time-domain propagation;
   - geodesic-spreading comparison;
   - disorder/localization analysis.

The guiding principle is:

> Do not make the topology itself electronically programmable. Put both reference geometries on the same board and make the analysis programmable.

This avoids hundreds of analog switches, their parasitics, and another debugging project.

---

# 1. Single-board architecture

Use two independent networks on one PCB:

- **Left:** 85-node Euclidean \(\{3,6\}\)
- **Right:** 85-node hyperbolic \(\{3,7\}\)

They share:

- ground;
- connector style;
- component families;
- measurement conventions;
- silkscreen conventions;
- excitation circuitry/interface;
- board environment.

They do **not** share graph nodes.

This gives a cleaner controlled comparison than using separate fabrication lots.

## Board dimensions

Target:

\[
\boxed{150\text{ mm} \times 130\text{ mm maximum}}
\]

Prefer smaller if routing permits.

Orient 130 mm along the T-962's 180 mm drawer dimension, leaving about 25 mm nominal clearance on each side.

Do not exceed 150 x 130 mm without explicit justification.

Use 2 layers unless routing proves impossible. Both graph families are planar, so crossings should not fundamentally require extra layers.

---

# 2. Component choice

For a one-and-done build, prioritize robust spectral resolution over saving the last ~$10.

Starting electrical scale:

\[
L \approx 1\,\mu\text H,\qquad C\approx330\,\text{pF}
\]

giving approximately a 1.4–9.6 MHz translated spectral window relative to the published 10 µH / 1 nF implementation.

The agent must compare at least:

### Robust option
A ~1 µH, ~5% inductor with Q around 50 near 8–10 MHz.

### Compact ultra-cheap option
Abracon AIML-0805-1R0K-T or similar:
- 0805
- 1 µH
- Q min ~45 at 10 MHz
- compact enough to make a dual-network PCB easier
- tolerance is ~10%, which is the main drawback.

The simulation must determine whether 10% L tolerance destroys mode identification. If it does, use the tighter-tolerance part.

Because this is intended as a one-time build, spending an extra ~$10–30 total for tighter L tolerance is preferable to needing another PCB revision.

Use C0G/NP0 capacitors. Prefer 1–2% if the cost delta is small.

---

# 3. Do not use a giant switch matrix

Do **not** attempt to switch every capacitor edge electronically.

An 85-node triangulated graph contains hundreds of edges. Making the union of Euclidean and hyperbolic edge sets electronically selectable would require hundreds of switching channels.

At ~1–10 MHz those switches introduce:

- on resistance;
- off capacitance;
- channel capacitance;
- routing complexity;
- control wiring;
- power rails;
- firmware;
- a new failure mode comparable in complexity to the experiment itself.

The cost advantage of sharing 85 cheap inductors is not worth it.

Two complete passive networks on one PCB are the simpler one-and-done solution.

---

# 4. Built-in reconfiguration: only where high-value

Reconfiguration should be sparse and intentional.

## 4.1 Excitation selector

Provide a simple header or jumper selection arrangement allowing a signal source to be routed manually to several preselected representative nodes on either geometry.

No active RF switching is required unless simulation shows a clear advantage.

Select sources corresponding to:

- center;
- intermediate shell;
- boundary;
- one or two symmetry-related points.

All nodes must still remain individually probeable.

## 4.2 Controlled defect bank

On each geometry reserve approximately 4–8 scientifically chosen edges for alternate coupling.

For each chosen edge provide footprints permitting:

- nominal \(C\);
- weaker coupling;
- stronger coupling;
- open edge.

Prefer solder-jumper / 0-ohm configuration unless a tiny DIP-switch implementation is clearly cleaner.

The board need not make every edge mutable.

## 4.3 Boundary-condition bank

Do not add one switch per boundary node.

Instead, reserve alternate termination footprints and group a *small number* of representative boundary-condition experiments where mathematically meaningful.

Default assembly should implement the same Dirichlet-like boundary condition used by the reference experiment.

The PCB should be modifiable later without cutting traces, but V1 measurement should require no modification.

---

# 5. What one board gives us

The following previously staged items are now **one experiment**.

## A. Euclidean vs. hyperbolic spectra

Measure resonances and recover the characteristic spectral reordering.

## B. Spatial eigenmodes

Measure node amplitudes/transfer functions at each resonance.

## C. Heat kernel and heat trace

Derived from the measured eigenpairs:

\[
K(t)=e^{-tQ}
\]

and

\[
\operatorname{Tr}e^{-tQ}
=\sum_\beta e^{-tq_\beta}.
\]

No additional hardware.

## D. Spectral zeta

\[
\zeta_Q(s)=\sum_{q_\beta\ne0}q_\beta^{-s}.
\]

No additional hardware.

## E. Green's function / resolvent

Driven response already gives access to the inverse circuit Laplacian / resolvent-like response.

Measure transfer functions between selected node pairs.

## F. Time-domain propagation

Inject the same localized pulse into both halves and scan the wavefront.

## G. Geodesic spreading

Compare wavefront spreading / arrival structure from nearby starting points in flat and negatively curved networks.

## H. Disorder / localization

Use measured component disorder plus the defect bank.

All of these should be treated as outputs of the same physical board, not future PCB revisions.

---

# 6. What should NOT be forced onto this PCB

Do not try to include:

- full Hodge \(L_1\) hardware;
- topolectrical nodal-knot circuitry;
- event-horizon / nonlinear transmission-line circuitry;
- active hyperbolic topological-band hardware;
- a sphere/torus/genus-2 network merely to claim extensibility.

Those require sufficiently different operators/couplings that including them would compromise the simplicity of the main experiment.

However, the software pipeline should generalize to arbitrary graph Laplacians so that a later board, if ever justified, is mostly a topology change.

---

# 7. Simulation-before-layout requirements

Before PCB freeze, answer:

1. Can two 85-node networks fit cleanly in <=150 x 130 mm?
2. Can they fit with the preferred tighter-tolerance inductors?
3. Does an 0805 Q~45 / 10% inductor remain usable after Monte Carlo disorder?
4. If not, what is the cheapest 5% part whose Q is sufficient?
5. Is 330 pF still the best C after probe and trace capacitance are included?
6. What resonances are expected across the accessible frequency range?
7. Which 4–8 defect edges are most mathematically informative?
8. Which excitation nodes best expose the Euclidean/hyperbolic contrast?
9. What measurement sequence reconstructs enough eigenvectors for the derived heat-kernel/zeta/Green-function analysis?

Do not freeze PCB dimensions until graph placement has been automatically attempted.

---

# 8. Layout requirements

Use scripted graph placement as the starting point.

For each half:

- preserve recognizable graph shells;
- label every node;
- place the inductor at/near its node;
- place coupling capacitors along graph edges;
- expose a probe pad for every node;
- include nearby ground access;
- keep high-parasitic test structures away from sensitive nodes;
- avoid large copper beneath long high-impedance graph edges unless simulation shows it is harmless.

Add clear silkscreen:

- `EUCLIDEAN`
- `HYPERBOLIC`
- node IDs
- shell/radius index
- designated source nodes
- designated defect edges.

---

# 9. Agent deliverables

Produce:

- one KiCad project for the combined board;
- one schematic containing both networks;
- one PCB <=150 x 130 mm;
- BOM;
- stencil/paste outputs;
- manufacturing outputs;
- graph adjacency files;
- automatic graph-to-KiCad generation where practical;
- automatic PCB-netlist-vs-target-graph verification;
- Monte Carlo/Q/probe-loading simulations;
- time-domain simulations;
- a measurement script/procedure;
- post-processing for spectrum, eigenvectors, heat trace, spectral zeta, Green's functions, and propagation.

---

# 10. Decision criterion

The desired endpoint is:

\[
\boxed{\text{One PCB + one reflow session + many mathematical experiments}}
\]

Do not optimize for the absolute smallest BOM if doing so creates a significant chance of another hardware revision.

The design should favor:
- passive components;
- generous test access;
- robust Q;
- controlled tolerances;
- simple measurement;
- analysis flexibility.

The main distinction from the prior plan is that **Euclidean and hyperbolic hardware are fabricated together**, while nearly all later “extensions” are extracted from the same measured eigenpairs and transfer functions rather than implemented as separate boards.

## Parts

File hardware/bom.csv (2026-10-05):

Reference | Value | Footprint | DNP | Role | MPN
L1 | 1u | Inductor_SMD:L_0805_2012Metric | False | E00 inductor; Abracon AIML-0805-1R0K-T 10% Q>=45 at 10MHz | AIML-0805-1R0K-T
L2 | 1u | Inductor_SMD:L_0805_2012Metric | False | E01 inductor; Abracon AIML-0805-1R0K-T 10% Q>=45 at 10MHz | AIML-0805-1R0K-T
L3 | 1u | Inductor_SMD:L_0805_2012Metric | False | E02 inductor; Abracon AIML-0805-1R0K-T 10% Q>=45 at 10MHz | AIML-0805-1R0K-T
L4 | 1u | Inductor_SMD:L_0805_2012Metric | False | E03 inductor; Abracon AIML-0805-1R0K-T 10% Q>=45 at 10MHz | AIML-0805-1R0K-T
L5 | 1u | Inductor_SMD:L_0805_2012Metric | False | E04 inductor; Abracon AIML-0805-1R0K-T 10% Q>=45 at 10MHz | AIML-0805-1R0K-T
L6 | 1u | Inductor_SMD:L_0805_2012Metric | False | E05 inductor; Abracon AIML-0805-1R0K-T 10% Q>=45 at 10MHz | AIML-0805-1R0K-T
L7 | 1u | Inductor_SMD:L_0805_2012Metric | False | E06 inductor; Abracon AIML-0805-1R0K-T 10% Q>=45 at 10MHz | AIML-0805-1R0K-T
L8 | 1u | Inductor_SMD:L_0805_2012Metric | False | E07 inductor; Abracon AIML-0805-1R0K-T 10% Q>=45 at 10MHz | AIML-0805-1R0K-T
L9 | 1u | Inductor_SMD:L_0805_2012Metric | False | E08 inductor; Abracon AIML-0805-1R0K-T 10% Q>=45 at 10MHz | AIML-0805-1R0K-T
L10 | 1u | Inductor_SMD:L_0805_2012Metric | False | E09 inductor; Abracon AIML-0805-1R0K-T 10% Q>=45 at 10MHz | AIML-0805-1R0K-T
L11 | 1u | Inductor_SMD:L_0805_2012Metric | False | E10 inductor; Abracon AIML-0805-1R0K-T 10% Q>=45 at 10MHz | AIML-0805-1R0K-T
L12 | 1u | Inductor_SMD:L_0805_2012Metric | False | E11 inductor; Abracon AIML-0805-1R0K-T 10% Q>=45 at 10MHz | AIML-0805-1R0K-T
L13 | 1u | Inductor_SMD:L_0805_2012Metric | False | E12 inductor; Abracon AIML-0805-1R0K-T 10% Q>=45 at 10MHz | AIML-0805-1R0K-T
L14 | 1u | Inductor_SMD:L_0805_2012Metric | False | E13 inductor; Abracon AIML-0805-1R0K-T 10% Q>=45 at 10MHz | AIML-0805-1R0K-T
L15 | 1u | Inductor_SMD:L_0805_2012Metric | False | E14 inductor; Abracon AIML-0805-1R0K-T 10% Q>=45 at 10MHz | AIML-0805-1R0K-T
L16 | 1u | Inductor_SMD:L_0805_2012Metric | False | E15 inductor; Abracon AIML-0805-1R0K-T 10% Q>=45 at 10MHz | AIML-0805-1R0K-T
L17 | 1u | Inductor_SMD:L_0805_2012Metric | False | E16 inductor; Abracon AIML-0805-1R0K-T 10% Q>=45 at 10MHz | AIML-0805-1R0K-T
L18 | 1u | Inductor_SMD:L_0805_2012Metric | False | E17 inductor; Abracon AIML-0805-1R0K-T 10% Q>=45 at 10MHz | AIML-0805-1R0K-T
L19 | 1u | Inductor_SMD:L_0805_2012Metric | False | E18 inductor; Abracon AIML-0805-1R0K-T 10% Q>=45 at 10MHz | AIML-0805-1R0K-T
L20 | 1u | Inductor_SMD:L_0805_2012Metric | False | E19 inductor; Abracon AIML-0805-1R0K-T 10% Q>=45 at 10MHz | AIML-0805-1R0K-T
L21 | 1u | Inductor_SMD:L_0805_2012Metric | False | E20 inductor; Abracon AIML-0805-1R0K-T 10% Q>=45 at 10MHz | AIML-0805-1R0K-T
L22 | 1u | Inductor_SMD:L_0805_2012Metric | False | E21 inductor; Abracon AIML-0805-1R0K-T 10% Q>=45 at 10MHz | AIML-0805-1R0K-T
L23 | 1u | Inductor_SMD:L_0805_2012Metric | False | E22 inductor; Abracon AIML-0805-1R0K-T 10% Q>=45 at 10MHz | AIML-0805-1R0K-T
L24 | 1u | Inductor_SMD:L_0805_2012Metric | False | E23 inductor; Abracon AIML-0805-1R0K-T 10% Q>=45 at 10MHz | AIML-0805-1R0K-T
L25 | 1u | Inductor_SMD:L_0805_2012Metric | False | E24 inductor; Abracon AIML-0805-1R0K-T 10% Q>=45 at 10MHz | AIML-0805-1R0K-T
L26 | 1u | Inductor_SMD:L_0805_2012Metric | False | E25 inductor; Abracon AIML-0805-1R0K-T 10% Q>=45 at 10MHz | AIML-0805-1R0K-T
L27 | 1u | Inductor_SMD:L_0805_2012Metric | False | E26 inductor; Abracon AIML-0805-1R0K-T 10% Q>=45 at 10MHz | AIML-0805-1R0K-T
L28 | 1u | Inductor_SMD:L_0805_2012Metric | False | E27 inductor; Abracon AIML-0805-1R0K-T 10% Q>=45 at 10MHz | AIML-0805-1R0K-T
L29 | 1u | Inductor_SMD:L_0805_2012Metric | False | E28 inductor; Abracon AIML-0805-1R0K-T 10% Q>=45 at 10MHz | AIML-0805-1R0K-T
L30 | 1u | Inductor_SMD:L_0805_2012Metric | False | E29 inductor; Abracon AIML-0805-1R0K-T 10% Q>=45 at 10MHz | AIML-0805-1R0K-T
L31 | 1u | Inductor_SMD:L_0805_2012Metric | False | E30 inductor; Abracon AIML-0805-1R0K-T 10% Q>=45 at 10MHz | AIML-0805-1R0K-T
L32 | 1u | Inductor_SMD:L_0805_2012Metric | False | E31 inductor; Abracon AIML-0805-1R0K-T 10% Q>=45 at 10MHz | AIML-0805-1R0K-T
L33 | 1u | Inductor_SMD:L_0805_2012Metric | False | E32 inductor; Abracon AIML-0805-1R0K-T 10% Q>=45 at 10MHz | AIML-0805-1R0K-T
L34 | 1u | Inductor_SMD:L_0805_2012Metric | False | E33 inductor; Abracon AIML-0805-1R0K-T 10% Q>=45 at 10MHz | AIML-0805-1R0K-T
L35 | 1u | Inductor_SMD:L_0805_2012Metric | False | E34 inductor; Abracon AIML-0805-1R0K-T 10% Q>=45 at 10MHz | AIML-0805-1R0K-T
L36 | 1u | Inductor_SMD:L_0805_2012Metric | False | E35 inductor; Abracon AIML-0805-1R0K-T 10% Q>=45 at 10MHz | AIML-0805-1R0K-T
L37 | 1u | Inductor_SMD:L_0805_2012Metric | False | E36 inductor; Abracon AIML-0805-1R0K-T 10% Q>=45 at 10MHz | AIML-0805-1R0K-T
L38 | 1u | Inductor_SMD:L_0805_2012Metric | False | E37 inductor; Abracon AIML-0805-1R0K-T 10% Q>=45 at 10MHz | AIML-0805-1R0K-T
L39 | 1u | Inductor_SMD:L_0805_2012Metric | False | E38 inductor; Abracon AIML-0805-1R0K-T 10% Q>=45 at 10MHz | AIML-0805-1R0K-T
L40 | 1u | Inductor_SMD:L_0805_2012Metric | False | E39 inductor; Abracon AIML-0805-1R0K-T 10% Q>=45 at 10MHz | AIML-0805-1R0K-T
L41 | 1u | Inductor_SMD:L_0805_2012Metric | False | E40 inductor; Abracon AIML-0805-1R0K-T 10% Q>=45 at 10MHz | AIML-0805-1R0K-T
L42 | 1u | Inductor_SMD:L_0805_2012Metric | False | E41 inductor; Abracon AIML-0805-1R0K-T 10% Q>=45 at 10MHz | AIML-0805-1R0K-T
L43 | 1u | Inductor_SMD:L_0805_2012Metric | False | E42 inductor; Abracon AIML-0805-1R0K-T 10% Q>=45 at 10MHz | AIML-0805-1R0K-T
L44 | 1u | Inductor_SMD:L_0805_2012Metric | False | E43 inductor; Abracon AIML-0805-1R0K-T 10% Q>=45 at 10MHz | AIML-0805-1R0K-T
L45 | 1u | Inductor_SMD:L_0805_2012Metric | False | E44 inductor; Abracon AIML-0805-1R0K-T 10% Q>=45 at 10MHz | AIML-0805-1R0K-T
L46 | 1u | Inductor_SMD:L_0805_2012Metric | False | E45 inductor; Abracon AIML-0805-1R0K-T 10% Q>=45 at 10MHz | AIML-0805-1R0K-T
L47 | 1u | Inductor_SMD:L_0805_2012Metric | False | E46 inductor; Abracon AIML-0805-1R0K-T 10% Q>=45 at 10MHz | AIML-0805-1R0K-T
L48 | 1u | Inductor_SMD:L_0805_2012Metric | False | E47 inductor; Abracon AIML-0805-1R0K-T 10% Q>=45 at 10MHz | AIML-0805-1R0K-T
L49 | 1u | Inductor_SMD:L_0805_2012Metric | False | E48 inductor; Abracon AIML-0805-1R0K-T 10% Q>=45 at 10MHz | AIML-0805-1R0K-T
L50 | 1u | Inductor_SMD:L_0805_2012Metric | False | E49 inductor; Abracon AIML-0805-1R0K-T 10% Q>=45 at 10MHz | AIML-0805-1R0K-T
L51 | 1u | Inductor_SMD:L_0805_2012Metric | False | E50 inductor; Abracon AIML-0805-1R0K-T 10% Q>=45 at 10MHz | AIML-0805-1R0K-T
L52 | 1u | Inductor_SMD:L_0805_2012Metric | False | E51 inductor; Abracon AIML-0805-1R0K-T 10% Q>=45 at 10MHz | AIML-0805-1R0K-T
L53 | 1u | Inductor_SMD:L_0805_2012Metric | False | E52 inductor; Abracon AIML-0805-1R0K-T 10% Q>=45 at 10MHz | AIML-0805-1R0K-T
L54 | 1u | Inductor_SMD:L_0805_2012Metric | False | E53 inductor; Abracon AIML-0805-1R0K-T 10% Q>=45 at 10MHz | AIML-0805-1R0K-T
L55 | 1u | Inductor_SMD:L_0805_2012Metric | False | E54 inductor; Abracon AIML-0805-1R0K-T 10% Q>=45 at 10MHz | AIML-0805-1R0K-T
L56 | 1u | Inductor_SMD:L_0805_2012Metric | False | E55 inductor; Abracon AIML-0805-1R0K-T 10% Q>=45 at 10MHz | AIML-0805-1R0K-T
C1 | 330p | Capacitor_SMD:C_0603_1608Metric | False | E55 boundary coupling 1/1 | CC0603JRNPO9BN331
L57 | 1u | Inductor_SMD:L_0805_2012Metric | False | E56 inductor; Abracon AIML-0805-1R0K-T 10% Q>=45 at 10MHz | AIML-0805-1R0K-T
C2 | 330p | Capacitor_SMD:C_0603_1608Metric | False | E56 boundary coupling 1/1 | CC0603JRNPO9BN331
L58 | 1u | Inductor_SMD:L_0805_2012Metric | False | E57 inductor; Abracon AIML-0805-1R0K-T 10% Q>=45 at 10MHz | AIML-0805-1R0K-T
C3 | 330p | Capacitor_SMD:C_0603_1608Metric | False | E57 boundary coupling 1/1 | CC0603JRNPO9BN331
L59 | 1u | Inductor_SMD:L_0805_2012Metric | False | E58 inductor; Abracon AIML-0805-1R0K-T 10% Q>=45 at 10MHz | AIML-0805-1R0K-T
C4 | 330p | Capacitor_SMD:C_0603_1608Metric | False | E58 boundary coupling 1/1 | CC0603JRNPO9BN331
L60 | 1u | Inductor_SMD:L_0805_2012Metric | False | E59 inductor; Abracon AIML-0805-1R0K-T 10% Q>=45 at 10MHz | AIML-0805-1R0K-T
C5 | 330p | Capacitor_SMD:C_0603_1608Metric | False | E59 boundary coupling 1/1 | CC0603JRNPO9BN331
L61 | 1u | Inductor_SMD:L_0805_2012Metric | False | E60 inductor; Abracon AIML-0805-1R0K-T 10% Q>=45 at 10MHz | AIML-0805-1R0K-T
C6 | 330p | Capacitor_SMD:C_0603_1608Metric | False | E60 boundary coupling 1/1 | CC0603JRNPO9BN331
L62 | 1u | Inductor_SMD:L_0805_2012Metric | False | E61 inductor; Abracon AIML-0805-1R0K-T 10% Q>=45 at 10MHz | AIML-0805-1R0K-T
C7 | 330p | Capacitor_SMD:C_0603_1608Metric | False | E61 boundary coupling 1/2 | CC0603JRNPO9BN331
C8 | 330p | Capacitor_SMD:C_0603_1608Metric | False | E61 boundary coupling 2/2 | CC0603JRNPO9BN331
L63 | 1u | Inductor_SMD:L_0805_2012Metric | False | E62 inductor; Abracon AIML-0805-1R0K-T 10% Q>=45 at 10MHz | AIML-0805-1R0K-T
C9 | 330p | Capacitor_SMD:C_0603_1608Metric | False | E62 boundary coupling 1/2 | CC0603JRNPO9BN331
C10 | 330p | Capacitor_SMD:C_0603_1608Metric | False | E62 boundary coupling 2/2 | CC0603JRNPO9BN331
L64 | 1u | Inductor_SMD:L_0805_2012Metric | False | E63 inductor; Abracon AIML-0805-1R0K-T 10% Q>=45 at 10MHz | AIML-0805-1R0K-T
C11 | 330p | Capacitor_SMD:C_0603_1608Metric | False | E63 boundary coupling 1/2 | CC0603JRNPO9BN331
C12 | 330p | Capacitor_SMD:C_0603_1608Metric | False | E63 boundary coupling 2/2 | CC0603JRNPO9BN331
L65 | 1u | Inductor_SMD:L_0805_2012Metric | False | E64 inductor; Abracon AIML-0805-1R0K-T 10% Q>=45 at 10MHz | AIML-0805-1R0K-T
C13 | 330p | Capacitor_SMD:C_0603_1608Metric | False | E64 boundary coupling 1/2 | CC0603JRNPO9BN331
C14 | 330p | Capacitor_SMD:C_0603_1608Metric | False | E64 boundary coupling 2/2 | CC0603JRNPO9BN331
L66 | 1u | Inductor_SMD:L_0805_2012Metric | False | E65 inductor; Abracon AIML-0805-1R0K-T 10% Q>=45 at 10MHz | AIML-0805-1R0K-T
C15 | 330p | Capacitor_SMD:C_0603_1608Metric | False | E65 boundary coupling 1/2 | CC0603JRNPO9BN331
C16 | 330p | Capacitor_SMD:C_0603_1608Metric | False | E65 boundary coupling 2/2 | CC0603JRNPO9BN331
L67 | 1u | Inductor_SMD:L_0805_2012Metric | False | E66 inductor; Abracon AIML-0805-1R0K-T 10% Q>=45 at 10MHz | AIML-0805-1R0K-T
C17 | 330p | Capacitor_SMD:C_0603_1608Metric | False | E66 boundary coupling 1/2 | CC0603JRNPO9BN331
C18 | 330p | Capacitor_SMD:C_0603_1608Metric | False | E66 boundary coupling 2/2 | CC0603JRNPO9BN331
L68 | 1u | Inductor_SMD:L_0805_2012Metric | False | E67 inductor; Abracon AIML-0805-1R0K-T 10% Q>=45 at 10MHz | AIML-0805-1R0K-T
C19 | 330p | Capacitor_SMD:C_0603_1608Metric | False | E67 boundary coupling 1/2 | CC0603JRNPO9BN331
C20 | 330p | Capacitor_SMD:C_0603_1608Metric | False | E67 boundary coupling 2/2 | CC0603JRNPO9BN331
L69 | 1u | Inductor_SMD:L_0805_2012Metric | False | E68 inductor; Abracon AIML-0805-1R0K-T 10% Q>=45 at 10MHz | AIML-0805-1R0K-T
C21 | 330p | Capacitor_SMD:C_0603_1608Metric | False | E68 boundary coupling 1/2 | CC0603JRNPO9BN331
C22 | 330p | Capacitor_SMD:C_0603_1608Metric | False | E68 boundary coupling 2/2 | CC0603JRNPO9BN331
L70 | 1u | Inductor_SMD:L_0805_2012Metric | False | E69 inductor; Abracon AIML-0805-1R0K-T 10% Q>=45 at 10MHz | AIML-0805-1R0K-T
C23 | 330p | Capacitor_SMD:C_0603_1608Metric | False | E69 boundary coupling 1/2 | CC0603JRNPO9BN331
C24 | 330p | Capacitor_SMD:C_0603_1608Metric | False | E69 boundary coupling 2/2 | CC0603JRNPO9BN331
L71 | 1u | Inductor_SMD:L_0805_2012Metric | False | E70 inductor; Abracon AIML-0805-1R0K-T 10% Q>=45 at 10MHz | AIML-0805-1R0K-T
C25 | 330p | Capacitor_SMD:C_0603_1608Metric | False | E70 boundary coupling 1/2 | CC0603JRNPO9BN331
C26 | 330p | Capacitor_SMD:C_0603_1608Metric | False | E70 boundary coupling 2/2 | CC0603JRNPO9BN331
L72 | 1u | Inductor_SMD:L_0805_2012Metric | False | E71 inductor; Abracon AIML-0805-1R0K-T 10% Q>=45 at 10MHz | AIML-0805-1R0K-T
C27 | 330p | Capacitor_SMD:C_0603_1608Metric | False | E71 boundary coupling 1/2 | CC0603JRNPO9BN331
C28 | 330p | Capacitor_SMD:C_0603_1608Metric | False | E71 boundary coupling 2/2 | CC0603JRNPO9BN331
L73 | 1u | Inductor_SMD:L_0805_2012Metric | False | E72 inductor; Abracon AIML-0805-1R0K-T 10% Q>=45 at 10MHz | AIML-0805-1R0K-T
C29 | 330p | Capacitor_SMD:C_0603_1608Metric | False | E72 boundary coupling 1/2 | CC0603JRNPO9BN331
C30 | 330p | Capacitor_SMD:C_0603_1608Metric | False | E72 boundary coupling 2/2 | CC0603JRNPO9BN331
L74 | 1u | Inductor_SMD:L_0805_2012Metric | False | E73 inductor; Abracon AIML-0805-1R0K-T 10% Q>=45 at 10MHz | AIML-0805-1R0K-T
C31 | 330p | Capacitor_SMD:C_0603_1608Metric | False | E73 boundary coupling 1/3 | CC0603JRNPO9BN331
C32 | 330p | Capacitor_SMD:C_0603_1608Metric | False | E73 boundary coupling 2/3 | CC0603JRNPO9BN331
C33 | 330p | Capacitor_SMD:C_0603_1608Metric | False | E73 boundary coupling 3/3 | CC0603JRNPO9BN331
L75 | 1u | Inductor_SMD:L_0805_2012Metric | False | E74 inductor; Abracon AIML-0805-1R0K-T 10% Q>=45 at 10MHz | AIML-0805-1R0K-T
C34 | 330p | Capacitor_SMD:C_0603_1608Metric | False | E74 boundary coupling 1/3 | CC0603JRNPO9BN331
C35 | 330p | Capacitor_SMD:C_0603_1608Metric | False | E74 boundary coupling 2/3 | CC0603JRNPO9BN331
C36 | 330p | Capacitor_SMD:C_0603_1608Metric | False | E74 boundary coupling 3/3 | CC0603JRNPO9BN331
L76 | 1u | Inductor_SMD:L_0805_2012Metric | False | E75 inductor; Abracon AIML-0805-1R0K-T 10% Q>=45 at 10MHz | AIML-0805-1R0K-T
C37 | 330p | Capacitor_SMD:C_0603_1608Metric | False | E75 boundary coupling 1/3 | CC0603JRNPO9BN331
C38 | 330p | Capacitor_SMD:C_0603_1608Metric | False | E75 boundary coupling 2/3 | CC0603JRNPO9BN331
C39 | 330p | Capacitor_SMD:C_0603_1608Metric | False | E75 boundary coupling 3/3 | CC0603JRNPO9BN331
L77 | 1u | Inductor_SMD:L_0805_2012Metric | False | E76 inductor; Abracon AIML-0805-1R0K-T 10% Q>=45 at 10MHz | AIML-0805-1R0K-T
C40 | 330p | Capacitor_SMD:C_0603_1608Metric | False | E76 boundary coupling 1/3 | CC0603JRNPO9BN331
C41 | 330p | Capacitor_SMD:C_0603_1608Metric | False | E76 boundary coupling 2/3 | CC0603JRNPO9BN331
C42 | 330p | Capacitor_SMD:C_0603_1608Metric | False | E76 boundary coupling 3/3 | CC0603JRNPO9BN331
L78 | 1u | Inductor_SMD:L_0805_2012Metric | False | E77 inductor; Abracon AIML-0805-1R0K-T 10% Q>=45 at 10MHz | AIML-0805-1R0K-T
C43 | 330p | Capacitor_SMD:C_0603_1608Metric | False | E77 boundary coupling 1/3 | CC0603JRNPO9BN331
C44 | 330p | Capacitor_SMD:C_0603_1608Metric | False | E77 boundary coupling 2/3 | CC0603JRNPO9BN331
C45 | 330p | Capacitor_SMD:C_0603_1608Metric | False | E77 boundary coupling 3/3 | CC0603JRNPO9BN331
L79 | 1u | Inductor_SMD:L_0805_2012Metric | False | E78 inductor; Abracon AIML-0805-1R0K-T 10% Q>=45 at 10MHz | AIML-0805-1R0K-T
C46 | 330p | Capacitor_SMD:C_0603_1608Metric | False | E78 boundary coupling 1/3 | CC0603JRNPO9BN331
C47 | 330p | Capacitor_SMD:C_0603_1608Metric | False | E78 boundary coupling 2/3 | CC0603JRNPO9BN331
C48 | 330p | Capacitor_SMD:C_0603_1608Metric | False | E78 boundary coupling 3/3 | CC0603JRNPO9BN331
L80 | 1u | Inductor_SMD:L_0805_2012Metric | False | E79 inductor; Abracon AIML-0805-1R0K-T 10% Q>=45 at 10MHz | AIML-0805-1R0K-T
C49 | 330p | Capacitor_SMD:C_0603_1608Metric | False | E79 boundary coupling 1/3 | CC0603JRNPO9BN331
C50 | 330p | Capacitor_SMD:C_0603_1608Metric | False | E79 boundary coupling 2/3 | CC0603JRNPO9BN331
C51 | 330p | Capacitor_SMD:C_0603_1608Metric | False | E79 boundary coupling 3/3 | CC0603JRNPO9BN331
L81 | 1u | Inductor_SMD:L_0805_2012Metric | False | E80 inductor; Abracon AIML-0805-1R0K-T 10% Q>=45 at 10MHz | AIML-0805-1R0K-T
C52 | 330p | Capacitor_SMD:C_0603_1608Metric | False | E80 boundary coupling 1/3 | CC0603JRNPO9BN331
C53 | 330p | Capacitor_SMD:C_0603_1608Metric | False | E80 boundary coupling 2/3 | CC0603JRNPO9BN331
C54 | 330p | Capacitor_SMD:C_0603_1608Metric | False | E80 boundary coupling 3/3 | CC0603JRNPO9BN331
L82 | 1u | Inductor_SMD:L_0805_2012Metric | False | E81 inductor; Abracon AIML-0805-1R0K-T 10% Q>=45 at 10MHz | AIML-0805-1R0K-T
C55 | 330p | Capacitor_SMD:C_0603_1608Metric | False | E81 boundary coupling 1/3 | CC0603JRNPO9BN331
C56 | 330p | Capacitor_SMD:C_0603_1608Metric | False | E81 boundary coupling 2/3 | CC0603JRNPO9BN331
C57 | 330p | Capacitor_SMD:C_0603_1608Metric | False | E81 boundary coupling 3/3 | CC0603JRNPO9BN331
L83 | 1u | Inductor_SMD:L_0805_2012Metric | False | E82 inductor; Abracon AIML-0805-1R0K-T 10% Q>=45 at 10MHz | AIML-0805-1R0K-T
C58 | 330p | Capacitor_SMD:C_0603_1608Metric | False | E82 boundary coupling 1/3 | CC0603JRNPO9BN331
C59 | 330p | Capacitor_SMD:C_0603_1608Metric | False | E82 boundary coupling 2/3 | CC0603JRNPO9BN331
C60 | 330p | Capacitor_SMD:C_0603_1608Metric | False | E82 boundary coupling 3/3 | CC0603JRNPO9BN331
L84 | 1u | Inductor_SMD:L_0805_2012Metric | False | E83 inductor; Abracon AIML-0805-1R0K-T 10% Q>=45 at 10MHz | AIML-0805-1R0K-T
C61 | 330p | Capacitor_SMD:C_0603_1608Metric | False | E83 boundary coupling 1/3 | CC0603JRNPO9BN331
C62 | 330p | Capacitor_SMD:C_0603_1608Metric | False | E83 boundary coupling 2/3 | CC0603JRNPO9BN331
C63 | 330p | Capacitor_SMD:C_0603_1608Metric | False | E83 boundary coupling 3/3 | CC0603JRNPO9BN331
L85 | 1u | Inductor_SMD:L_0805_2012Metric | False | E84 inductor; Abracon AIML-0805-1R0K-T 10% Q>=45 at 10MHz | AIML-0805-1R0K-T
C64 | 330p | Capacitor_SMD:C_0603_1608Metric | False | E84 boundary coupling 1/3 | CC0603JRNPO9BN331
C65 | 330p | Capacitor_SMD:C_0603_1608Metric | False | E84 boundary coupling 2/3 | CC0603JRNPO9BN331
C66 | 330p | Capacitor_SMD:C_0603_1608Metric | False | E84 boundary coupling 3/3 | CC0603JRNPO9BN331
C67 | 330p | Capacitor_SMD:C_0603_1608Metric | False | E edge 0-1 defect D1: replace 165p/open or parallel 330p | CC0603JRNPO9BN331
C68 | 330p | Capacitor_SMD:C_0603_1608Metric | True | E edge 0-1 defect D1: replace 165p/open or parallel 330p parallel | CC0603JRNPO9BN331
C69 | 330p | Capacitor_SMD:C_0603_1608Metric | False | E edge 0-2 | CC0603JRNPO9BN331
C70 | 330p | Capacitor_SMD:C_0603_1608Metric | False | E edge 0-3 | CC0603JRNPO9BN331
C71 | 330p | Capacitor_SMD:C_0603_1608Metric | False | E edge 0-4 | CC0603JRNPO9BN331
C72 | 330p | Capacitor_SMD:C_0603_1608Metric | False | E edge 0-5 | CC0603JRNPO9BN331
C73 | 330p | Capacitor_SMD:C_0603_1608Metric | False | E edge 0-6 | CC0603JRNPO9BN331
C74 | 330p | Capacitor_SMD:C_0603_1608Metric | False | E edge 1-2 | CC0603JRNPO9BN331
C75 | 330p | Capacitor_SMD:C_0603_1608Metric | False | E edge 1-6 | CC0603JRNPO9BN331
C76 | 330p | Capacitor_SMD:C_0603_1608Metric | False | E edge 1-7 | CC0603JRNPO9BN331
C77 | 330p | Capacitor_SMD:C_0603_1608Metric | False | E edge 1-8 | CC0603JRNPO9BN331
C78 | 330p | Capacitor_SMD:C_0603_1608Metric | False | E edge 1-13 | CC0603JRNPO9BN331
C79 | 330p | Capacitor_SMD:C_0603_1608Metric | False | E edge 2-3 | CC0603JRNPO9BN331
C80 | 330p | Capacitor_SMD:C_0603_1608Metric | False | E edge 2-8 | CC0603JRNPO9BN331
C81 | 330p | Capacitor_SMD:C_0603_1608Metric | False | E edge 2-9 | CC0603JRNPO9BN331
C82 | 330p | Capacitor_SMD:C_0603_1608Metric | False | E edge 2-14 | CC0603JRNPO9BN331
C83 | 330p | Capacitor_SMD:C_0603_1608Metric | False | E edge 3-4 | CC0603JRNPO9BN331
C84 | 330p | Capacitor_SMD:C_0603_1608Metric | False | E edge 3-9 | CC0603JRNPO9BN331
C85 | 330p | Capacitor_SMD:C_0603_1608Metric | False | E edge 3-10 | CC0603JRNPO9BN331
C86 | 330p | Capacitor_SMD:C_0603_1608Metric | False | E edge 3-15 | CC0603JRNPO9BN331
C87 | 330p | Capacitor_SMD:C_0603_1608Metric | False | E edge 4-5 | CC0603JRNPO9BN331
C88 | 330p | Capacitor_SMD:C_0603_1608Metric | False | E edge 4-10 | CC0603JRNPO9BN331
C89 | 330p | Capacitor_SMD:C_0603_1608Metric | False | E edge 4-11 | CC0603JRNPO9BN331
C90 | 330p | Capacitor_SMD:C_0603_1608Metric | False | E edge 4-16 | CC0603JRNPO9BN331
C91 | 330p | Capacitor_SMD:C_0603_1608Metric | False | E edge 5-6 | CC0603JRNPO9BN331
C92 | 330p | Capacitor_SMD:C_0603_1608Metric | False | E edge 5-11 | CC0603JRNPO9BN331
C93 | 330p | Capacitor_SMD:C_0603_1608Metric | False | E edge 5-12 | CC0603JRNPO9BN331
C94 | 330p | Capacitor_SMD:C_0603_1608Metric | False | E edge 5-17 | CC0603JRNPO9BN331
C95 | 330p | Capacitor_SMD:C_0603_1608Metric | False | E edge 6-7 | CC0603JRNPO9BN331
C96 | 330p | Capacitor_SMD:C_0603_1608Metric | False | E edge 6-12 | CC0603JRNPO9BN331
C97 | 330p | Capacitor_SMD:C_0603_1608Metric | False | E edge 6-18 | CC0603JRNPO9BN331
C98 | 330p | Capacitor_SMD:C_0603_1608Metric | False | E edge 7-13 | CC0603JRNPO9BN331
C99 | 330p | Capacitor_SMD:C_0603_1608Metric | False | E edge 7-18 | CC0603JRNPO9BN331
C100 | 330p | Capacitor_SMD:C_0603_1608Metric | False | E edge 7-19 | CC0603JRNPO9BN331
C101 | 330p | Capacitor_SMD:C_0603_1608Metric | False | E edge 7-20 | CC0603JRNPO9BN331
C102 | 330p | Capacitor_SMD:C_0603_1608Metric | False | E edge 8-13 | CC0603JRNPO9BN331
C103 | 330p | Capacitor_SMD:C_0603_1608Metric | False | E edge 8-14 | CC0603JRNPO9BN331
C104 | 330p | Capacitor_SMD:C_0603_1608Metric | False | E edge 8-21 | CC0603JRNPO9BN331
C105 | 330p | Capacitor_SMD:C_0603_1608Metric | False | E edge 8-22 | CC0603JRNPO9BN331
C106 | 330p | Capacitor_SMD:C_0603_1608Metric | False | E edge 9-14 | CC0603JRNPO9BN331
C107 | 330p | Capacitor_SMD:C_0603_1608Metric | False | E edge 9-15 defect D2: replace 165p/open or parallel 330p | CC0603JRNPO9BN331
C108 | 330p | Capacitor_SMD:C_0603_1608Metric | True | E edge 9-15 defect D2: replace 165p/open or parallel 330p parallel | CC0603JRNPO9BN331
C109 | 330p | Capacitor_SMD:C_0603_1608Metric | False | E edge 9-23 | CC0603JRNPO9BN331
C110 | 330p | Capacitor_SMD:C_0603_1608Metric | False | E edge 9-24 | CC0603JRNPO9BN331
C111 | 330p | Capacitor_SMD:C_0603_1608Metric | False | E edge 10-15 | CC0603JRNPO9BN331
C112 | 330p | Capacitor_SMD:C_0603_1608Metric | False | E edge 10-16 | CC0603JRNPO9BN331
C113 | 330p | Capacitor_SMD:C_0603_1608Metric | False | E edge 10-25 | CC0603JRNPO9BN331
C114 | 330p | Capacitor_SMD:C_0603_1608Metric | False | E edge 10-26 | CC0603JRNPO9BN331
C115 | 330p | Capacitor_SMD:C_0603_1608Metric | False | E edge 11-16 | CC0603JRNPO9BN331
C116 | 330p | Capacitor_SMD:C_0603_1608Metric | False | E edge 11-17 | CC0603JRNPO9BN331
C117 | 330p | Capacitor_SMD:C_0603_1608Metric | False | E edge 11-27 | CC0603JRNPO9BN331
C118 | 330p | Capacitor_SMD:C_0603_1608Metric | False | E edge 11-28 | CC0603JRNPO9BN331
C119 | 330p | Capacitor_SMD:C_0603_1608Metric | False | E edge 12-17 | CC0603JRNPO9BN331
C120 | 330p | Capacitor_SMD:C_0603_1608Metric | False | E edge 12-18 | CC0603JRNPO9BN331
C121 | 330p | Capacitor_SMD:C_0603_1608Metric | False | E edge 12-29 | CC0603JRNPO9BN331
C122 | 330p | Capacitor_SMD:C_0603_1608Metric | False | E edge 12-30 | CC0603JRNPO9BN331
C123 | 330p | Capacitor_SMD:C_0603_1608Metric | False | E edge 13-20 | CC0603JRNPO9BN331
C124 | 330p | Capacitor_SMD:C_0603_1608Metric | False | E edge 13-21 | CC0603JRNPO9BN331
C125 | 330p | Capacitor_SMD:C_0603_1608Metric | False | E edge 13-31 | CC0603JRNPO9BN331
C126 | 330p | Capacitor_SMD:C_0603_1608Metric | False | E edge 14-22 | CC0603JRNPO9BN331
C127 | 330p | Capacitor_SMD:C_0603_1608Metric | False | E edge 14-23 | CC0603JRNPO9BN331
C128 | 330p | Capacitor_SMD:C_0603_1608Metric | False | E edge 14-32 defect D3: replace 165p/open or parallel 330p | CC0603JRNPO9BN331
C129 | 330p | Capacitor_SMD:C_0603_1608Metric | True | E edge 14-32 defect D3: replace 165p/open or parallel 330p parallel | CC0603JRNPO9BN331
C130 | 330p | Capacitor_SMD:C_0603_1608Metric | False | E edge 15-24 | CC0603JRNPO9BN331
C131 | 330p | Capacitor_SMD:C_0603_1608Metric | False | E edge 15-25 | CC0603JRNPO9BN331
C132 | 330p | Capacitor_SMD:C_0603_1608Metric | False | E edge 15-33 | CC0603JRNPO9BN331
C133 | 330p | Capacitor_SMD:C_0603_1608Metric | False | E edge 16-26 | CC0603JRNPO9BN331
C134 | 330p | Capacitor_SMD:C_0603_1608Metric | False | E edge 16-27 | CC0603JRNPO9BN331
C135 | 330p | Capacitor_SMD:C_0603_1608Metric | False | E edge 16-34 | CC0603JRNPO9BN331
C136 | 330p | Capacitor_SMD:C_0603_1608Metric | False | E edge 17-28 | CC0603JRNPO9BN331
C137 | 330p | Capacitor_SMD:C_0603_1608Metric | False | E edge 17-29 | CC0603JRNPO9BN331
C138 | 330p | Capacitor_SMD:C_0603_1608Metric | False | E edge 17-35 | CC0603JRNPO9BN331
C139 | 330p | Capacitor_SMD:C_0603_1608Metric | False | E edge 18-19 | CC0603JRNPO9BN331
C140 | 330p | Capacitor_SMD:C_0603_1608Metric | False | E edge 18-30 | CC0603JRNPO9BN331
C141 | 330p | Capacitor_SMD:C_0603_1608Metric | False | E edge 18-36 defect D6: replace 165p/open or parallel 330p | CC0603JRNPO9BN331
C142 | 330p | Capacitor_SMD:C_0603_1608Metric | True | E edge 18-36 defect D6: replace 165p/open or parallel 330p parallel | CC0603JRNPO9BN331
C143 | 330p | Capacitor_SMD:C_0603_1608Metric | False | E edge 19-20 | CC0603JRNPO9BN331
C144 | 330p | Capacitor_SMD:C_0603_1608Metric | False | E edge 19-36 | CC0603JRNPO9BN331
C145 | 330p | Capacitor_SMD:C_0603_1608Metric | False | E edge 19-37 | CC0603JRNPO9BN331
C146 | 330p | Capacitor_SMD:C_0603_1608Metric | False | E edge 19-43 | CC0603JRNPO9BN331
C147 | 330p | Capacitor_SMD:C_0603_1608Metric | False | E edge 20-31 | CC0603JRNPO9BN331
C148 | 330p | Capacitor_SMD:C_0603_1608Metric | False | E edge 20-37 | CC0603JRNPO9BN331
C149 | 330p | Capacitor_SMD:C_0603_1608Metric | False | E edge 20-44 | CC0603JRNPO9BN331
C150 | 330p | Capacitor_SMD:C_0603_1608Metric | False | E edge 21-22 | CC0603JRNPO9BN331
C151 | 330p | Capacitor_SMD:C_0603_1608Metric | False | E edge 21-31 | CC0603JRNPO9BN331
C152 | 330p | Capacitor_SMD:C_0603_1608Metric | False | E edge 21-38 | CC0603JRNPO9BN331
C153 | 330p | Capacitor_SMD:C_0603_1608Metric | False | E edge 21-45 | CC0603JRNPO9BN331
C154 | 330p | Capacitor_SMD:C_0603_1608Metric | False | E edge 22-32 | CC0603JRNPO9BN331
C155 | 330p | Capacitor_SMD:C_0603_1608Metric | False | E edge 22-38 | CC0603JRNPO9BN331
C156 | 330p | Capacitor_SMD:C_0603_1608Metric | False | E edge 22-46 | CC0603JRNPO9BN331
C157 | 330p | Capacitor_SMD:C_0603_1608Metric | False | E edge 23-24 | CC0603JRNPO9BN331
C158 | 330p | Capacitor_SMD:C_0603_1608Metric | False | E edge 23-32 | CC0603JRNPO9BN331
C159 | 330p | Capacitor_SMD:C_0603_1608Metric | False | E edge 23-39 | CC0603JRNPO9BN331
C160 | 330p | Capacitor_SMD:C_0603_1608Metric | False | E edge 23-47 | CC0603JRNPO9BN331
C161 | 330p | Capacitor_SMD:C_0603_1608Metric | False | E edge 24-33 | CC0603JRNPO9BN331
C162 | 330p | Capacitor_SMD:C_0603_1608Metric | False | E edge 24-39 | CC0603JRNPO9BN331
C163 | 330p | Capacitor_SMD:C_0603_1608Metric | False | E edge 24-48 | CC0603JRNPO9BN331
C164 | 330p | Capacitor_SMD:C_0603_1608Metric | False | E edge 25-26 | CC0603JRNPO9BN331
C165 | 330p | Capacitor_SMD:C_0603_1608Metric | False | E edge 25-33 | CC0603JRNPO9BN331
C166 | 330p | Capacitor_SMD:C_0603_1608Metric | False | E edge 25-40 | CC0603JRNPO9BN331
C167 | 330p | Capacitor_SMD:C_0603_1608Metric | False | E edge 25-49 | CC0603JRNPO9BN331
C168 | 330p | Capacitor_SMD:C_0603_1608Metric | False | E edge 26-34 | CC0603JRNPO9BN331
C169 | 330p | Capacitor_SMD:C_0603_1608Metric | False | E edge 26-40 | CC0603JRNPO9BN331
C170 | 330p | Capacitor_SMD:C_0603_1608Metric | False | E edge 26-50 | CC0603JRNPO9BN331
C171 | 330p | Capacitor_SMD:C_0603_1608Metric | False | E edge 27-28 | CC0603JRNPO9BN331
C172 | 330p | Capacitor_SMD:C_0603_1608Metric | False | E edge 27-34 | CC0603JRNPO9BN331
C173 | 330p | Capacitor_SMD:C_0603_1608Metric | False | E edge 27-41 | CC0603JRNPO9BN331
C174 | 330p | Capacitor_SMD:C_0603_1608Metric | False | E edge 27-51 | CC0603JRNPO9BN331
C175 | 330p | Capacitor_SMD:C_0603_1608Metric | False | E edge 28-35 | CC0603JRNPO9BN331
C176 | 330p | Capacitor_SMD:C_0603_1608Metric | False | E edge 28-41 | CC0603JRNPO9BN331
C177 | 330p | Capacitor_SMD:C_0603_1608Metric | False | E edge 28-52 | CC0603JRNPO9BN331
C178 | 330p | Capacitor_SMD:C_0603_1608Metric | False | E edge 29-30 | CC0603JRNPO9BN331
C179 | 330p | Capacitor_SMD:C_0603_1608Metric | False | E edge 29-35 | CC0603JRNPO9BN331
C180 | 330p | Capacitor_SMD:C_0603_1608Metric | False | E edge 29-42 | CC0603JRNPO9BN331
C181 | 330p | Capacitor_SMD:C_0603_1608Metric | False | E edge 29-53 | CC0603JRNPO9BN331
C182 | 330p | Capacitor_SMD:C_0603_1608Metric | False | E edge 30-36 | CC0603JRNPO9BN331
C183 | 330p | Capacitor_SMD:C_0603_1608Metric | False | E edge 30-42 | CC0603JRNPO9BN331
C184 | 330p | Capacitor_SMD:C_0603_1608Metric | False | E edge 30-54 | CC0603JRNPO9BN331
C185 | 330p | Capacitor_SMD:C_0603_1608Metric | False | E edge 31-44 | CC0603JRNPO9BN331
C186 | 330p | Capacitor_SMD:C_0603_1608Metric | False | E edge 31-45 | CC0603JRNPO9BN331
C187 | 330p | Capacitor_SMD:C_0603_1608Metric | False | E edge 31-55 | CC0603JRNPO9BN331
C188 | 330p | Capacitor_SMD:C_0603_1608Metric | False | E edge 32-46 | CC0603JRNPO9BN331
C189 | 330p | Capacitor_SMD:C_0603_1608Metric | False | E edge 32-47 | CC0603JRNPO9BN331
C190 | 330p | Capacitor_SMD:C_0603_1608Metric | False | E edge 32-56 | CC0603JRNPO9BN331
C191 | 330p | Capacitor_SMD:C_0603_1608Metric | False | E edge 33-48 | CC0603JRNPO9BN331
C192 | 330p | Capacitor_SMD:C_0603_1608Metric | False | E edge 33-49 | CC0603JRNPO9BN331
C193 | 330p | Capacitor_SMD:C_0603_1608Metric | False | E edge 33-57 | CC0603JRNPO9BN331
C194 | 330p | Capacitor_SMD:C_0603_1608Metric | False | E edge 34-50 | CC0603JRNPO9BN331
C195 | 330p | Capacitor_SMD:C_0603_1608Metric | False | E edge 34-51 | CC0603JRNPO9BN331
C196 | 330p | Capacitor_SMD:C_0603_1608Metric | False | E edge 34-58 | CC0603JRNPO9BN331
C197 | 330p | Capacitor_SMD:C_0603_1608Metric | False | E edge 35-52 | CC0603JRNPO9BN331
C198 | 330p | Capacitor_SMD:C_0603_1608Metric | False | E edge 35-53 | CC0603JRNPO9BN331
C199 | 330p | Capacitor_SMD:C_0603_1608Metric | False | E edge 35-59 | CC0603JRNPO9BN331
C200 | 330p | Capacitor_SMD:C_0603_1608Metric | False | E edge 36-43 | CC0603JRNPO9BN331
C201 | 330p | Capacitor_SMD:C_0603_1608Metric | False | E edge 36-54 | CC0603JRNPO9BN331
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

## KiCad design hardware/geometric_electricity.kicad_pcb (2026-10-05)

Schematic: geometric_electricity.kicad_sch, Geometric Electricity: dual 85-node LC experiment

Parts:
C1, C2, C3, C4, C5, C6, C7, C8, C9, C10, C11, C12, C13, C14, C15, C16, C17, C18, C19, C20, C21, C22, C23, C24, C25, C26, C27, C28, C29, C30, C31, C32, C33, C34, C35, C36, C37, C38, C39, C40, C41, C42, C43, C44, C45, C46, C47, C48, C49, C50, C51, C52, C53, C54, C55, C56, C57, C58, C59, C60, C61, C62, C63, C64, C65, C66, C67, C69, C70, C71, C72, C73, C74, C75, C76, C77, C78, C79, C80, C81, C82, C83, C84, C85, C86, C87, C88, C89, C90, C91, C92, C93, C94, C95, C96, C97, C98, C99, C100, C101, C102, C103, C104, C105, C106, C107, C109, C110, C111, C112, C113, C114, C115, C116, C117, C118, C119, C120, C121, C122, C123, C124, C125, C126, C127, C128, C130, C131, C132, C133, C134, C135, C136, C137, C138, C139, C140, C141, C143, C144, C145, C146, C147, C148, C149, C150, C151, C152, C153, C154, C155, C156, C157, C158, C159, C160, C161, C162, C163, C164, C165, C166, C167, C168, C169, C170, C171, C172, C173, C174, C175, C176, C177, C178, C179, C180, C181, C182, C183, C184, C185, C186, C187, C188, C189, C190, C191, C192, C193, C194, C195, C196, C197, C198, C199, C200, C201, C202, C203, C204, C205, C206, C207, C208, C210, C211, C212, C213, C214, C215, C216, C217, C218, C219, C220, C221, C222, C223, C224, C225, C226, C227, C228, C229, C230, C231, C232, C233, C234, C235, C236, C237, C238, C239, C240, C241, C242, C243, C244, C245, C246, C247, C248, C249, C250, C251, C252, C253, C254, C255, C256, C257, C258, C259, C260, C261, C262, C263, C264, C265, C266, C267, C268, C269, C270, C271, C273, C274, C275, C276, C277, C278, C279, C280, C281, C282, C283, C284, C285, C286, C287, C288, C289, C290, C291, C292, C293, C294, C295, C296, C297, C298, C299, C300, C301, C302, C303, C304, C305, C306, C307, C308, C309, C310, C311, C312, C313, C314, C315, C316, C317, C318, C319, C320, C321, C322, C323, C324, C325, C326, C327, C328, C329, C330, C331, C332, C333, C334, C335, C336, C337, C338, C339, C340, C341, C342, C343, C344, C345, C346, C347, C348, C349, C350, C351, C352, C353, C354, C355, C356, C357, C358, C359, C360, C361, C362, C363, C364, C365, C366, C367, C368, C369, C370, C371, C372, C373, C374, C375, C376, C377, C378, C379, C380, C381, C382, C383, C384, C385, C386, C387, C388, C389, C390, C391, C392, C393, C394, C395, C396, C397, C398, C399, C400, C401, C402, C403, C404, C405, C406, C407, C408, C409, C410, C411, C412, C413, C414, C415, C416, C417, C418, C419, C420, C421, C422, C423, C424, C425, C426, C427, C428, C429, C430, C431, C432, C433, C434, C435, C436, C437, C438, C439, C440, C441, C442, C443, C444, C445, C446, C447, C448, C449, C450, C451, C452, C453, C454, C455, C456, C457, C458, C459, C460, C461, C462, C463, C464, C465, C466, C467, C468, C469, C470, C471, C472, C473, C474, C475, C476, C477, C478, C479, C480, C481, C482, C483, C484, C485, C486, C487, C488, C489, C490, C491, C492, C493, C494, C495, C496, C497, C498, C499, C501, C502, C503, C504, C505, C506, C507, C508, C509, C511, C512, C513, C514, C515, C516, C517, C518, C519, C520, C521, C522, C523, C524, C525, C526, C527, C528, C529, C531, C532, C533, C534, C535, C537, C538, C539, C540, C542, C543, C544, C545, C546, C547, C548, C549, C550, C551, C552, C553, C554, C555, C556, C557, C558, C559, C560, C561, C562, C563, C564, C565, C566, C567, C568, C569, C570, C571, C572, C573, C574, C575, C576, C577, C578, C579, C580, C581, C582, C583, C584, C585, C586, C587, C588, C589, C590, C591, C593, C594, C595, C596, C597, C598, C599, C600, C601, C602, C603, C604, C605, C606, C607, C608, C609, C610, C611, C612, C613, C614, C615, C616, C617, C618, C619, C620, C621, C622, C623, C624, C625, C626, C627, C628, C629, C630, C631, C632, C633, C634, C635, C636, C637, C638, C639, C640, C641, C642, C643, C644, C645, C646, C647, C648, C649, C650, C651, C652, C653, C654, C655, C656, C657, C658, C659, C660, C661, C662, C663, C664, C665, C666, C667, C668, C669, C670, C671, C672, C673, C674, C675, C676, C677, C678, C679, C680, C681, C682, C683, C684, C685, C686, C687, C688, C689, C690, C691, C692, C693, C694, C695, C696, C697, C698, C699: 330p; C_0603_1608Metric
C68, C108, C129, C142, C209, C272, C500, C510, C530, C536, C541, C592: 330p; C_0603_1608Metric; not fitted
J1, J2: SOURCE; PinHeader_1x02_P2.54mm_Vertical
L1, L2, L3, L4, L5, L6, L7, L8, L9, L10, L11, L12, L13, L14, L15, L16, L17, L18, L19, L20, L21, L22, L23, L24, L25, L26, L27, L28, L29, L30, L31, L32, L33, L34, L35, L36, L37, L38, L39, L40, L41, L42, L43, L44, L45, L46, L47, L48, L49, L50, L51, L52, L53, L54, L55, L56, L57, L58, L59, L60, L61, L62, L63, L64, L65, L66, L67, L68, L69, L70, L71, L72, L73, L74, L75, L76, L77, L78, L79, L80, L81, L82, L83, L84, L85, L86, L87, L88, L89, L90, L91, L92, L93, L94, L95, L96, L97, L98, L99, L100, L101, L102, L103, L104, L105, L106, L107, L108, L109, L110, L111, L112, L113, L114, L115, L116, L117, L118, L119, L120, L121, L122, L123, L124, L125, L126, L127, L128, L129, L130, L131, L132, L133, L134, L135, L136, L137, L138, L139, L140, L141, L142, L143, L144, L145, L146, L147, L148, L149, L150, L151, L152, L153, L154, L155, L156, L157, L158, L159, L160, L161, L162, L163, L164, L165, L166, L167, L168, L169, L170: 1u; L_0805_2012Metric
R1, R2: 1k; R_0603_1608Metric
TP1: E00; TestPoint_Pad_D1.0mm
TP2, TP4, TP6, TP8, TP10, TP12, TP14, TP16, TP18, TP20, TP22, TP24, TP26, TP28, TP30, TP32, TP34, TP36, TP38, TP40, TP42, TP44, TP46, TP48, TP50, TP52, TP54, TP56, TP58, TP60, TP62, TP64, TP66, TP68, TP70, TP72, TP74, TP76, TP78, TP80, TP82, TP84, TP86, TP88, TP90, TP92, TP94, TP96, TP98, TP100, TP102, TP104, TP106, TP108, TP110, TP112, TP114, TP116, TP118, TP120, TP122, TP124, TP126, TP128, TP130, TP132, TP134, TP136, TP138, TP140, TP142, TP144, TP146, TP148, TP150, TP152, TP154, TP156, TP158, TP160, TP162, TP164, TP166, TP168, TP170, TP174, TP176, TP178, TP180, TP182, TP184, TP186, TP188, TP190, TP192, TP194, TP196, TP198, TP200, TP202, TP204, TP206, TP208, TP210, TP212, TP214, TP216, TP218, TP220, TP222, TP224, TP226, TP228, TP230, TP232, TP234, TP236, TP238, TP240, TP242, TP244, TP246, TP248, TP250, TP252, TP254, TP256, TP258, TP260, TP262, TP264, TP266, TP268, TP270, TP272, TP274, TP276, TP278, TP280, TP282, TP284, TP286, TP288, TP290, TP292, TP294, TP296, TP298, TP300, TP302, TP304, TP306, TP308, TP310, TP312, TP314, TP316, TP318, TP320, TP322, TP324, TP326, TP328, TP330, TP332, TP334, TP336, TP338, TP340, TP342: GND; TestPoint_Pad_D1.0mm
TP3: E01; TestPoint_Pad_D1.0mm
TP5: E02; TestPoint_Pad_D1.0mm
TP7: E03; TestPoint_Pad_D1.0mm
TP9: E04; TestPoint_Pad_D1.0mm
TP11: E05; TestPoint_Pad_D1.0mm
TP13: E06; TestPoint_Pad_D1.0mm
TP15: E07; TestPoint_Pad_D1.0mm
TP17: E08; TestPoint_Pad_D1.0mm
TP19: E09; TestPoint_Pad_D1.0mm
TP21: E10; TestPoint_Pad_D1.0mm
TP23: E11; TestPoint_Pad_D1.0mm
TP25: E12; TestPoint_Pad_D1.0mm
TP27: E13; TestPoint_Pad_D1.0mm
TP29: E14; TestPoint_Pad_D1.0mm
TP31: E15; TestPoint_Pad_D1.0mm
TP33: E16; TestPoint_Pad_D1.0mm
TP35: E17; TestPoint_Pad_D1.0mm
TP37: E18; TestPoint_Pad_D1.0mm
TP39: E19; TestPoint_Pad_D1.0mm
TP41: E20; TestPoint_Pad_D1.0mm
TP43: E21; TestPoint_Pad_D1.0mm
TP45: E22; TestPoint_Pad_D1.0mm
TP47: E23; TestPoint_Pad_D1.0mm
TP49: E24; TestPoint_Pad_D1.0mm
TP51: E25; TestPoint_Pad_D1.0mm
TP53: E26; TestPoint_Pad_D1.0mm
TP55: E27; TestPoint_Pad_D1.0mm
TP57: E28; TestPoint_Pad_D1.0mm
TP59: E29; TestPoint_Pad_D1.0mm
TP61: E30; TestPoint_Pad_D1.0mm
TP63: E31; TestPoint_Pad_D1.0mm
TP65: E32; TestPoint_Pad_D1.0mm
TP67: E33; TestPoint_Pad_D1.0mm
TP69: E34; TestPoint_Pad_D1.0mm
TP71: E35; TestPoint_Pad_D1.0mm
TP73: E36; TestPoint_Pad_D1.0mm
TP75: E37; TestPoint_Pad_D1.0mm
TP77: E38; TestPoint_Pad_D1.0mm
TP79: E39; TestPoint_Pad_D1.0mm
TP81: E40; TestPoint_Pad_D1.0mm
TP83: E41; TestPoint_Pad_D1.0mm
TP85: E42; TestPoint_Pad_D1.0mm
TP87: E43; TestPoint_Pad_D1.0mm
TP89: E44; TestPoint_Pad_D1.0mm
TP91: E45; TestPoint_Pad_D1.0mm
TP93: E46; TestPoint_Pad_D1.0mm
TP95: E47; TestPoint_Pad_D1.0mm
TP97: E48; TestPoint_Pad_D1.0mm
TP99: E49; TestPoint_Pad_D1.0mm
TP101: E50; TestPoint_Pad_D1.0mm
TP103: E51; TestPoint_Pad_D1.0mm
TP105: E52; TestPoint_Pad_D1.0mm
TP107: E53; TestPoint_Pad_D1.0mm
TP109: E54; TestPoint_Pad_D1.0mm
TP111: E55; TestPoint_Pad_D1.0mm
TP113: E56; TestPoint_Pad_D1.0mm
TP115: E57; TestPoint_Pad_D1.0mm
TP117: E58; TestPoint_Pad_D1.0mm
TP119: E59; TestPoint_Pad_D1.0mm
TP121: E60; TestPoint_Pad_D1.0mm
TP123: E61; TestPoint_Pad_D1.0mm
TP125: E62; TestPoint_Pad_D1.0mm
TP127: E63; TestPoint_Pad_D1.0mm
TP129: E64; TestPoint_Pad_D1.0mm
TP131: E65; TestPoint_Pad_D1.0mm
TP133: E66; TestPoint_Pad_D1.0mm
TP135: E67; TestPoint_Pad_D1.0mm
TP137: E68; TestPoint_Pad_D1.0mm
TP139: E69; TestPoint_Pad_D1.0mm
TP141: E70; TestPoint_Pad_D1.0mm
TP143: E71; TestPoint_Pad_D1.0mm
TP145: E72; TestPoint_Pad_D1.0mm
TP147: E73; TestPoint_Pad_D1.0mm
TP149: E74; TestPoint_Pad_D1.0mm
TP151: E75; TestPoint_Pad_D1.0mm
TP153: E76; TestPoint_Pad_D1.0mm
TP155: E77; TestPoint_Pad_D1.0mm
TP157: E78; TestPoint_Pad_D1.0mm
TP159: E79; TestPoint_Pad_D1.0mm
TP161: E80; TestPoint_Pad_D1.0mm
TP163: E81; TestPoint_Pad_D1.0mm
TP165: E82; TestPoint_Pad_D1.0mm
TP167: E83; TestPoint_Pad_D1.0mm
TP169: E84; TestPoint_Pad_D1.0mm
TP171: E_DRIVE; TestPoint_Pad_D1.0mm
TP172: E_IN; TestPoint_Pad_D1.0mm
TP173: H00; TestPoint_Pad_D1.0mm
TP175: H01; TestPoint_Pad_D1.0mm
TP177: H02; TestPoint_Pad_D1.0mm
TP179: H03; TestPoint_Pad_D1.0mm
TP181: H04; TestPoint_Pad_D1.0mm
TP183: H05; TestPoint_Pad_D1.0mm
TP185: H06; TestPoint_Pad_D1.0mm
TP187: H07; TestPoint_Pad_D1.0mm
TP189: H08; TestPoint_Pad_D1.0mm
TP191: H09; TestPoint_Pad_D1.0mm
TP193: H10; TestPoint_Pad_D1.0mm
TP195: H11; TestPoint_Pad_D1.0mm
TP197: H12; TestPoint_Pad_D1.0mm
TP199: H13; TestPoint_Pad_D1.0mm
TP201: H14; TestPoint_Pad_D1.0mm
TP203: H15; TestPoint_Pad_D1.0mm
TP205: H16; TestPoint_Pad_D1.0mm
TP207: H17; TestPoint_Pad_D1.0mm
TP209: H18; TestPoint_Pad_D1.0mm
TP211: H19; TestPoint_Pad_D1.0mm
TP213: H20; TestPoint_Pad_D1.0mm
TP215: H21; TestPoint_Pad_D1.0mm
TP217: H22; TestPoint_Pad_D1.0mm
TP219: H23; TestPoint_Pad_D1.0mm
TP221: H24; TestPoint_Pad_D1.0mm
TP223: H25; TestPoint_Pad_D1.0mm
TP225: H26; TestPoint_Pad_D1.0mm
TP227: H27; TestPoint_Pad_D1.0mm
TP229: H28; TestPoint_Pad_D1.0mm
TP231: H29; TestPoint_Pad_D1.0mm
TP233: H30; TestPoint_Pad_D1.0mm
TP235: H31; TestPoint_Pad_D1.0mm
TP237: H32; TestPoint_Pad_D1.0mm
TP239: H33; TestPoint_Pad_D1.0mm
TP241: H34; TestPoint_Pad_D1.0mm
TP243: H35; TestPoint_Pad_D1.0mm
TP245: H36; TestPoint_Pad_D1.0mm
TP247: H37; TestPoint_Pad_D1.0mm
TP249: H38; TestPoint_Pad_D1.0mm
TP251: H39; TestPoint_Pad_D1.0mm
TP253: H40; TestPoint_Pad_D1.0mm
TP255: H41; TestPoint_Pad_D1.0mm
TP257: H42; TestPoint_Pad_D1.0mm
TP259: H43; TestPoint_Pad_D1.0mm
TP261: H44; TestPoint_Pad_D1.0mm
TP263: H45; TestPoint_Pad_D1.0mm
TP265: H46; TestPoint_Pad_D1.0mm
TP267: H47; TestPoint_Pad_D1.0mm
TP269: H48; TestPoint_Pad_D1.0mm
TP271: H49; TestPoint_Pad_D1.0mm
TP273: H50; TestPoint_Pad_D1.0mm
TP275: H51; TestPoint_Pad_D1.0mm
TP277: H52; TestPoint_Pad_D1.0mm
TP279: H53; TestPoint_Pad_D1.0mm
TP281: H54; TestPoint_Pad_D1.0mm
TP283: H55; TestPoint_Pad_D1.0mm
TP285: H56; TestPoint_Pad_D1.0mm
TP287: H57; TestPoint_Pad_D1.0mm
TP289: H58; TestPoint_Pad_D1.0mm
TP291: H59; TestPoint_Pad_D1.0mm
TP293: H60; TestPoint_Pad_D1.0mm
TP295: H61; TestPoint_Pad_D1.0mm
TP297: H62; TestPoint_Pad_D1.0mm
TP299: H63; TestPoint_Pad_D1.0mm
TP301: H64; TestPoint_Pad_D1.0mm
TP303: H65; TestPoint_Pad_D1.0mm
TP305: H66; TestPoint_Pad_D1.0mm
TP307: H67; TestPoint_Pad_D1.0mm
TP309: H68; TestPoint_Pad_D1.0mm
TP311: H69; TestPoint_Pad_D1.0mm
TP313: H70; TestPoint_Pad_D1.0mm
TP315: H71; TestPoint_Pad_D1.0mm
TP317: H72; TestPoint_Pad_D1.0mm
TP319: H73; TestPoint_Pad_D1.0mm
TP321: H74; TestPoint_Pad_D1.0mm
TP323: H75; TestPoint_Pad_D1.0mm
TP325: H76; TestPoint_Pad_D1.0mm
TP327: H77; TestPoint_Pad_D1.0mm
TP329: H78; TestPoint_Pad_D1.0mm
TP331: H79; TestPoint_Pad_D1.0mm
TP333: H80; TestPoint_Pad_D1.0mm
TP335: H81; TestPoint_Pad_D1.0mm
TP337: H82; TestPoint_Pad_D1.0mm
TP339: H83; TestPoint_Pad_D1.0mm
TP341: H84; TestPoint_Pad_D1.0mm
TP343: H_DRIVE; TestPoint_Pad_D1.0mm
TP344: H_IN; TestPoint_Pad_D1.0mm

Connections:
E00: C67.1, C68.1, C69.1, C70.1, C71.1, C72.1, C73.1, L1.1, TP1.1
E01: C67.2, C68.2, C74.1, C75.1, C76.1, C77.1, C78.1, L2.1, TP3.1
E02: C69.2, C74.2, C79.1, C80.1, C81.1, C82.1, L3.1, TP5.1
E03: C70.2, C79.2, C83.1, C84.1, C85.1, C86.1, L4.1, TP7.1
E04: C71.2, C83.2, C87.1, C88.1, C89.1, C90.1, L5.1, TP9.1
E05: C72.2, C87.2, C91.1, C92.1, C93.1, C94.1, L6.1, TP11.1
E06: C73.2, C75.2, C91.2, C95.1, C96.1, C97.1, L7.1, TP13.1
E07: C76.2, C95.2, C98.1, C99.1, C100.1, C101.1, L8.1, TP15.1
E08: C77.2, C80.2, C102.1, C103.1, C104.1, C105.1, L9.1, TP17.1
E09: C81.2, C84.2, C106.1, C107.1, C108.1, C109.1, C110.1, L10.1, TP19.1
E10: C85.2, C88.2, C111.1, C112.1, C113.1, C114.1, L11.1, TP21.1
E11: C89.2, C92.2, C115.1, C116.1, C117.1, C118.1, L12.1, TP23.1
E12: C93.2, C96.2, C119.1, C120.1, C121.1, C122.1, L13.1, TP25.1
E13: C78.2, C98.2, C102.2, C123.1, C124.1, C125.1, L14.1, TP27.1
E14: C82.2, C103.2, C106.2, C126.1, C127.1, C128.1, C129.1, L15.1, TP29.1
E15: C86.2, C107.2, C108.2, C111.2, C130.1, C131.1, C132.1, L16.1, TP31.1
E16: C90.2, C112.2, C115.2, C133.1, C134.1, C135.1, L17.1, TP33.1
E17: C94.2, C116.2, C119.2, C136.1, C137.1, C138.1, L18.1, TP35.1
E18: C97.2, C99.2, C120.2, C139.1, C140.1, C141.1, C142.1, L19.1, TP37.1
E19: C100.2, C139.2, C143.1, C144.1, C145.1, C146.1, L20.1, TP39.1
E20: C101.2, C123.2, C143.2, C147.1, C148.1, C149.1, L21.1, TP41.1
E21: C104.2, C124.2, C150.1, C151.1, C152.1, C153.1, L22.1, TP43.1
E22: C105.2, C126.2, C150.2, C154.1, C155.1, C156.1, L23.1, TP45.1
E23: C109.2, C127.2, C157.1, C158.1, C159.1, C160.1, L24.1, TP47.1
E24: C110.2, C130.2, C157.2, C161.1, C162.1, C163.1, L25.1, TP49.1
E25: C113.2, C131.2, C164.1, C165.1, C166.1, C167.1, L26.1, TP51.1
E26: C114.2, C133.2, C164.2, C168.1, C169.1, C170.1, L27.1, TP53.1
E27: C117.2, C134.2, C171.1, C172.1, C173.1, C174.1, L28.1, TP55.1
E28: C118.2, C136.2, C171.2, C175.1, C176.1, C177.1, L29.1, TP57.1
E29: C121.2, C137.2, C178.1, C179.1, C180.1, C181.1, L30.1, TP59.1
E30: C122.2, C140.2, C178.2, C182.1, C183.1, C184.1, L31.1, TP61.1
E31: C125.2, C147.2, C151.2, C185.1, C186.1, C187.1, L32.1, TP63.1
E32: C128.2, C129.2, C154.2, C158.2, C188.1, C189.1, C190.1, L33.1, TP65.1
E33: C132.2, C161.2, C165.2, C191.1, C192.1, C193.1, L34.1, TP67.1
E34: C135.2, C168.2, C172.2, C194.1, C195.1, C196.1, L35.1, TP69.1
E35: C138.2, C175.2, C179.2, C197.1, C198.1, C199.1, L36.1, TP71.1
E36: C141.2, C142.2, C144.2, C182.2, C200.1, C201.1, C202.1, L37.1, TP73.1
E37: C145.2, C148.2, C203.1, C204.1, C205.1, C206.1, L38.1, TP75.1
E38: C152.2, C155.2, C207.1, C208.1, C209.1, C210.1, C211.1, L39.1, TP77.1
E39: C159.2, C162.2, C212.1, C213.1, C214.1, C215.1, L40.1, TP79.1
E40: C166.2, C169.2, C216.1, C217.1, C218.1, C219.1, L41.1, TP81.1
E41: C173.2, C176.2, C220.1, C221.1, C222.1, C223.1, L42.1, TP83.1
E42: C180.2, C183.2, C224.1, C225.1, C226.1, C227.1, L43.1, TP85.1
E43: C146.2, C200.2, C203.2, C228.1, C229.1, C230.1, L44.1, TP87.1
E44: C149.2, C185.2, C204.2, C231.1, C232.1, C233.1, L45.1, TP89.1
E45: C153.2, C186.2, C207.2, C234.1, C235.1, C236.1, L46.1, TP91.1
E46: C156.2, C188.2, C208.2, C209.2, C237.1, C238.1, C239.1, L47.1, TP93.1
E47: C160.2, C189.2, C212.2, C240.1, C241.1, C242.1, L48.1, TP95.1
E48: C163.2, C191.2, C213.2, C243.1, C244.1, C245.1, L49.1, TP97.1
E49: C167.2, C192.2, C216.2, C246.1, C247.1, C248.1, L50.1, TP99.1
E50: C170.2, C194.2, C217.2, C249.1, C250.1, C251.1, L51.1, TP101.1
E51: C174.2, C195.2, C220.2, C252.1, C253.1, C254.1, L52.1, TP103.1
E52: C177.2, C197.2, C221.2, C255.1, C256.1, C257.1, L53.1, TP105.1
E53: C181.2, C198.2, C224.2, C258.1, C259.1, C260.1, L54.1, TP107.1
E54: C184.2, C201.2, C225.2, C261.1, C262.1, C263.1, L55.1, TP109.1
E55: C1.1, C187.2, C231.2, C234.2, C264.1, C265.1, L56.1, TP111.1
E56: C2.1, C190.2, C237.2, C240.2, C266.1, C267.1, L57.1, TP113.1
E57: C3.1, C193.2, C243.2, C246.2, C268.1, C269.1, L58.1, TP115.1
E58: C4.1, C196.2, C249.2, C252.2, C270.1, C271.1, C272.1, L59.1, TP117.1
E59: C5.1, C199.2, C255.2, C258.2, C273.1, C274.1, L60.1, TP119.1
E60: C6.1, C202.2, C228.2, C261.2, C275.1, C276.1, L61.1, TP121.1
E61: C7.1, C8.1, C205.2, C229.2, C277.1, C278.1, L62.1, TP123.1
E62: C9.1, C10.1, C206.2, C232.2, C277.2, C279.1, L63.1, TP125.1
E63: C11.1, C12.1, C210.2, C235.2, C280.1, C281.1, L64.1, TP127.1
E64: C13.1, C14.1, C211.2, C238.2, C280.2, C282.1, L65.1, TP129.1
E65: C15.1, C16.1, C214.2, C241.2, C283.1, C284.1, L66.1, TP131.1
E66: C17.1, C18.1, C215.2, C244.2, C283.2, C285.1, L67.1, TP133.1
E67: C19.1, C20.1, C218.2, C247.2, C286.1, C287.1, L68.1, TP135.1
E68: C21.1, C22.1, C219.2, C250.2, C286.2, C288.1, L69.1, TP137.1
E69: C23.1, C24.1, C222.2, C253.2, C289.1, C290.1, L70.1, TP139.1
E70: C25.1, C26.1, C223.2, C256.2, C289.2, C291.1, L71.1, TP141.1
E71: C27.1, C28.1, C226.2, C259.2, C292.1, C293.1, L72.1, TP143.1
E72: C29.1, C30.1, C227.2, C262.2, C292.2, C294.1, L73.1, TP145.1
E73: C31.1, C32.1, C33.1, C230.2, C275.2, C278.2, L74.1, TP147.1
E74: C34.1, C35.1, C36.1, C233.2, C264.2, C279.2, L75.1, TP149.1
E75: C37.1, C38.1, C39.1, C236.2, C265.2, C281.2, L76.1, TP151.1
E76: C40.1, C41.1, C42.1, C239.2, C266.2, C282.2, L77.1, TP153.1
E77: C43.1, C44.1, C45.1, C242.2, C267.2, C284.2, L78.1, TP155.1
E78: C46.1, C47.1, C48.1, C245.2, C268.2, C285.2, L79.1, TP157.1
E79: C49.1, C50.1, C51.1, C248.2, C269.2, C287.2, L80.1, TP159.1
E80: C52.1, C53.1, C54.1, C251.2, C270.2, C288.2, L81.1, TP161.1
E81: C55.1, C56.1, C57.1, C254.2, C271.2, C272.2, C290.2, L82.1, TP163.1
E82: C58.1, C59.1, C60.1, C257.2, C273.2, C291.2, L83.1, TP165.1
E83: C61.1, C62.1, C63.1, C260.2, C274.2, C293.2, L84.1, TP167.1
E84: C64.1, C65.1, C66.1, C263.2, C276.2, C294.2, L85.1, TP169.1
E_DRIVE: R1.2, TP171.1
E_IN: J1.1, R1.1, TP172.1
GND: C1.2, C2.2, C3.2, C4.2, C5.2, C6.2, C7.2, C8.2, C9.2, C10.2, C11.2, C12.2, C13.2, C14.2, C15.2, C16.2, C17.2, C18.2, C19.2, C20.2, C21.2, C22.2, C23.2, C24.2, C25.2, C26.2, C27.2, C28.2, C29.2, C30.2, C31.2, C32.2, C33.2, C34.2, C35.2, C36.2, C37.2, C38.2, C39.2, C40.2, C41.2, C42.2, C43.2, C44.2, C45.2, C46.2, C47.2, C48.2, C49.2, C50.2, C51.2, C52.2, C53.2, C54.2, C55.2, C56.2, C57.2, C58.2, C59.2, C60.2, C61.2, C62.2, C63.2, C64.2, C65.2, C66.2, C295.2, C296.2, C297.2, C298.2, C299.2, C300.2, C301.2, C302.2, C303.2, C304.2, C305.2, C306.2, C307.2, C308.2, C309.2, C310.2, C311.2, C312.2, C313.2, C314.2, C315.2, C316.2, C317.2, C318.2, C319.2, C320.2, C321.2, C322.2, C323.2, C324.2, C325.2, C326.2, C327.2, C328.2, C329.2, C330.2, C331.2, C332.2, C333.2, C334.2, C335.2, C336.2, C337.2, C338.2, C339.2, C340.2, C341.2, C342.2, C343.2, C344.2, C345.2, C346.2, C347.2, C348.2, C349.2, C350.2, C351.2, C352.2, C353.2, C354.2, C355.2, C356.2, C357.2, C358.2, C359.2, C360.2, C361.2, C362.2, C363.2, C364.2, C365.2, C366.2, C367.2, C368.2, C369.2, C370.2, C371.2, C372.2, C373.2, C374.2, C375.2, C376.2, C377.2, C378.2, C379.2, C380.2, C381.2, C382.2, C383.2, C384.2, C385.2, C386.2, C387.2, C388.2, C389.2, C390.2, C391.2, C392.2, C393.2, C394.2, C395.2, C396.2, C397.2, C398.2, C399.2, C400.2, C401.2, C402.2, C403.2, C404.2, C405.2, C406.2, C407.2, C408.2, C409.2, C410.2, C411.2, C412.2, C413.2, C414.2, C415.2, C416.2, C417.2, C418.2, C419.2, C420.2, C421.2, C422.2, C423.2, C424.2, C425.2, C426.2, C427.2, C428.2, C429.2, C430.2, C431.2, C432.2, C433.2, C434.2, C435.2, C436.2, C437.2, C438.2, C439.2, C440.2, C441.2, C442.2, C443.2, C444.2, C445.2, C446.2, C447.2, C448.2, C449.2, C450.2, C451.2, C452.2, C453.2, C454.2, C455.2, C456.2, C457.2, C458.2, C459.2, C460.2, C461.2, C462.2, C463.2, C464.2, C465.2, C466.2, C467.2, C468.2, C469.2, C470.2, C471.2, C472.2, C473.2, C474.2, C475.2, C476.2, C477.2, C478.2, C479.2, C480.2, C481.2, C482.2, C483.2, C484.2, C485.2, C486.2, C487.2, C488.2, C489.2, C490.2, C491.2, C492.2, C493.2, C494.2, C495.2, C496.2, C497.2, J1.2, J2.2, L1.2, L2.2, L3.2, L4.2, L5.2, L6.2, L7.2, L8.2, L9.2, L10.2, L11.2, L12.2, L13.2, L14.2, L15.2, L16.2, L17.2, L18.2, L19.2, L20.2, L21.2, L22.2, L23.2, L24.2, L25.2, L26.2, L27.2, L28.2, L29.2, L30.2, L31.2, L32.2, L33.2, L34.2, L35.2, L36.2, L37.2, L38.2, L39.2, L40.2, L41.2, L42.2, L43.2, L44.2, L45.2, L46.2, L47.2, L48.2, L49.2, L50.2, L51.2, L52.2, L53.2, L54.2, L55.2, L56.2, L57.2, L58.2, L59.2, L60.2, L61.2, L62.2, L63.2, L64.2, L65.2, L66.2, L67.2, L68.2, L69.2, L70.2, L71.2, L72.2, L73.2, L74.2, L75.2, L76.2, L77.2, L78.2, L79.2, L80.2, L81.2, L82.2, L83.2, L84.2, L85.2, L86.2, L87.2, L88.2, L89.2, L90.2, L91.2, L92.2, L93.2, L94.2, L95.2, L96.2, L97.2, L98.2, L99.2, L100.2, L101.2, L102.2, L103.2, L104.2, L105.2, L106.2, L107.2, L108.2, L109.2, L110.2, L111.2, L112.2, L113.2, L114.2, L115.2, L116.2, L117.2, L118.2, L119.2, L120.2, L121.2, L122.2, L123.2, L124.2, L125.2, L126.2, L127.2, L128.2, L129.2, L130.2, L131.2, L132.2, L133.2, L134.2, L135.2, L136.2, L137.2, L138.2, L139.2, L140.2, L141.2, L142.2, L143.2, L144.2, L145.2, L146.2, L147.2, L148.2, L149.2, L150.2, L151.2, L152.2, L153.2, L154.2, L155.2, L156.2, L157.2, L158.2, L159.2, L160.2, L161.2, L162.2, L163.2, L164.2, L165.2, L166.2, L167.2, L168.2, L169.2, L170.2, TP2.1, TP4.1, TP6.1, TP8.1, TP10.1, TP12.1, TP14.1, TP16.1, TP18.1, TP20.1, TP22.1, TP24.1, TP26.1, TP28.1, TP30.1, TP32.1, TP34.1, TP36.1, TP38.1, TP40.1, TP42.1, TP44.1, TP46.1, TP48.1, TP50.1, TP52.1, TP54.1, TP56.1, TP58.1, TP60.1, TP62.1, TP64.1, TP66.1, TP68.1, TP70.1, TP72.1, TP74.1, TP76.1, TP78.1, TP80.1, TP82.1, TP84.1, TP86.1, TP88.1, TP90.1, TP92.1, TP94.1, TP96.1, TP98.1, TP100.1, TP102.1, TP104.1, TP106.1, TP108.1, TP110.1, TP112.1, TP114.1, TP116.1, TP118.1, TP120.1, TP122.1, TP124.1, TP126.1, TP128.1, TP130.1, TP132.1, TP134.1, TP136.1, TP138.1, TP140.1, TP142.1, TP144.1, TP146.1, TP148.1, TP150.1, TP152.1, TP154.1, TP156.1, TP158.1, TP160.1, TP162.1, TP164.1, TP166.1, TP168.1, TP170.1, TP174.1, TP176.1, TP178.1, TP180.1, TP182.1, TP184.1, TP186.1, TP188.1, TP190.1, TP192.1, TP194.1, TP196.1, TP198.1, TP200.1, TP202.1, TP204.1, TP206.1, TP208.1, TP210.1, TP212.1, TP214.1, TP216.1, TP218.1, TP220.1, TP222.1, TP224.1, TP226.1, TP228.1, TP230.1, TP232.1, TP234.1, TP236.1, TP238.1, TP240.1, TP242.1, TP244.1, TP246.1, TP248.1, TP250.1, TP252.1, TP254.1, TP256.1, TP258.1, TP260.1, TP262.1, TP264.1, TP266.1, TP268.1, TP270.1, TP272.1, TP274.1, TP276.1, TP278.1, TP280.1, TP282.1, TP284.1, TP286.1, TP288.1, TP290.1, TP292.1, TP294.1, TP296.1, TP298.1, TP300.1, TP302.1, TP304.1, TP306.1, TP308.1, TP310.1, TP312.1, TP314.1, TP316.1, TP318.1, TP320.1, TP322.1, TP324.1, TP326.1, TP328.1, TP330.1, TP332.1, TP334.1, TP336.1, TP338.1, TP340.1, TP342.1
H00: C498.1, C499.1, C500.1, C501.1, C502.1, C503.1, C504.1, C505.1, L86.1, TP173.1
H01: C498.2, C506.1, C507.1, C508.1, C509.1, C510.1, C511.1, C512.1, L87.1, TP175.1
H02: C499.2, C500.2, C506.2, C513.1, C514.1, C515.1, C516.1, C517.1, L88.1, TP177.1
H03: C501.2, C513.2, C518.1, C519.1, C520.1, C521.1, C522.1, L89.1, TP179.1
H04: C502.2, C518.2, C523.1, C524.1, C525.1, C526.1, C527.1, L90.1, TP181.1
H05: C503.2, C523.2, C528.1, C529.1, C530.1, C531.1, C532.1, C533.1, L91.1, TP183.1
H06: C504.2, C528.2, C534.1, C535.1, C536.1, C537.1, C538.1, C539.1, L92.1, TP185.1
H07: C505.2, C507.2, C534.2, C540.1, C541.1, C542.1, C543.1, C544.1, L93.1, TP187.1
H08: C508.2, C514.2, C545.1, C546.1, C547.1, C548.1, C549.1, L94.1, TP189.1
H09: C515.2, C519.2, C550.1, C551.1, C552.1, C553.1, C554.1, L95.1, TP191.1
H10: C520.2, C524.2, C555.1, C556.1, C557.1, C558.1, C559.1, L96.1, TP193.1
H11: C525.2, C529.2, C530.2, C560.1, C561.1, C562.1, C563.1, C564.1, L97.1, TP195.1
H12: C531.2, C535.2, C536.2, C565.1, C566.1, C567.1, C568.1, C569.1, L98.1, TP197.1
H13: C537.2, C540.2, C541.2, C570.1, C571.1, C572.1, C573.1, C574.1, L99.1, TP199.1
H14: C509.2, C510.2, C542.2, C575.1, C576.1, C577.1, C578.1, C579.1, L100.1, TP201.1
H15: C511.2, C575.2, C580.1, C581.1, C582.1, C583.1, C584.1, L101.1, TP203.1
H16: C512.2, C545.2, C580.2, C585.1, C586.1, C587.1, C588.1, L102.1, TP205.1
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

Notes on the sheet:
DRAFT: 1uH / 330pF; AIML-0805-1R0K-T; Q>=45 at 10MHz; use 10x probes. All node labels are global within this sheet.

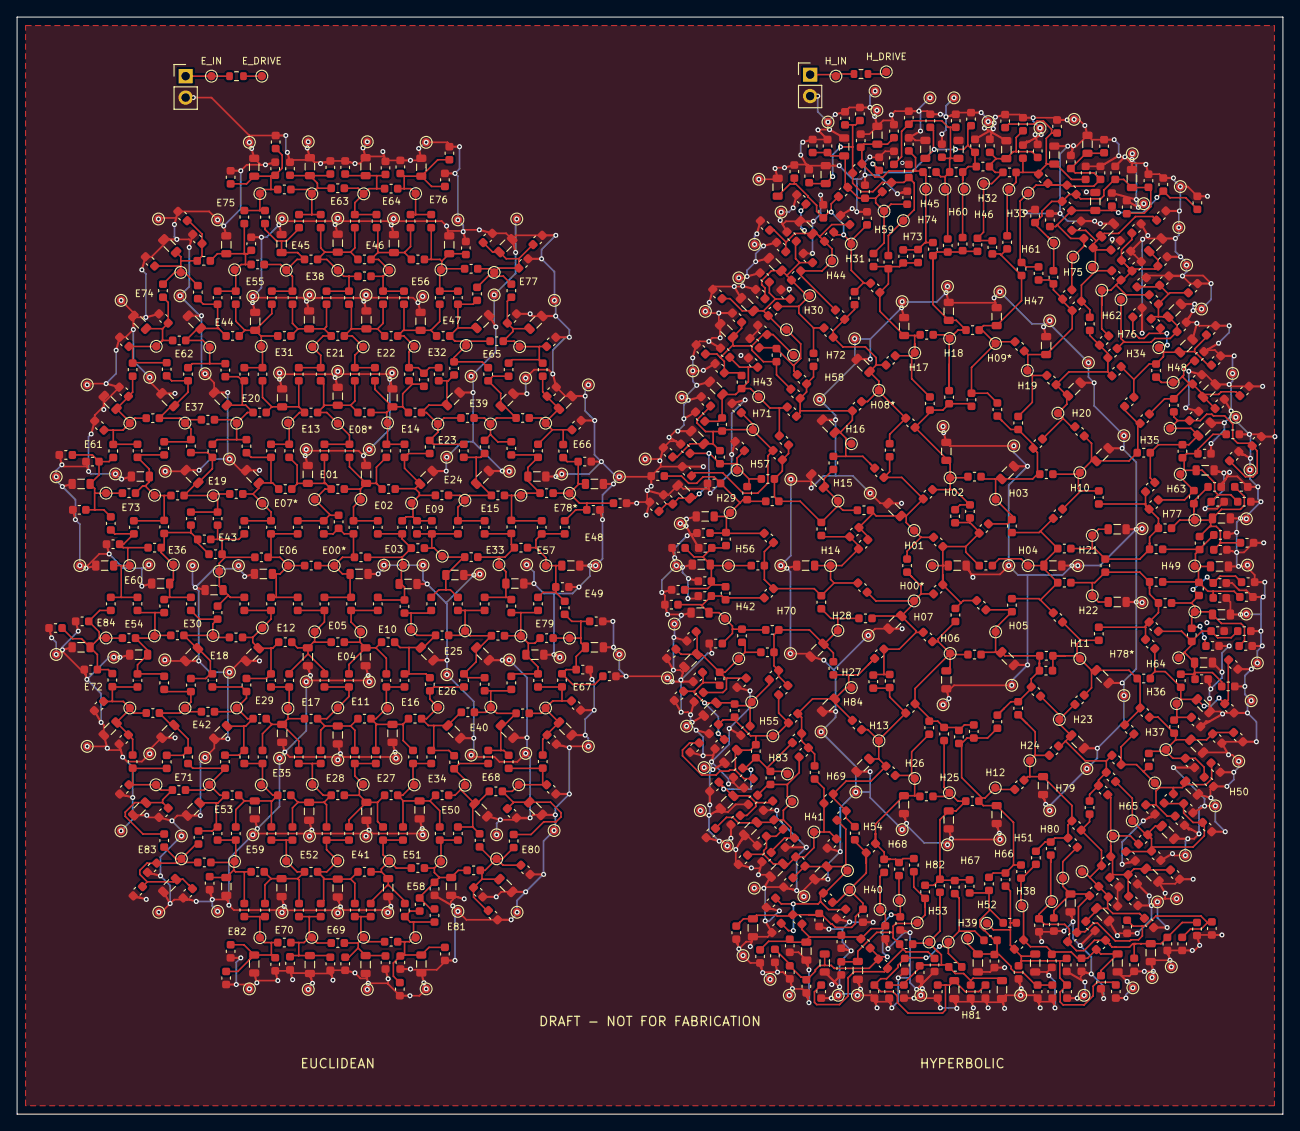
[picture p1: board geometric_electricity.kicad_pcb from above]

Board: 2 copper layers, 150.0 x 130.0 mm, 1217 parts (0 on the bottom side), 175 nets.

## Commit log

2026-10-05 accepting v0 design work.
    [bom.csv, geometric_electricity.kicad_pcb, geometric_electricity.kicad_sch]
2026-10-05 accepting updated bom
